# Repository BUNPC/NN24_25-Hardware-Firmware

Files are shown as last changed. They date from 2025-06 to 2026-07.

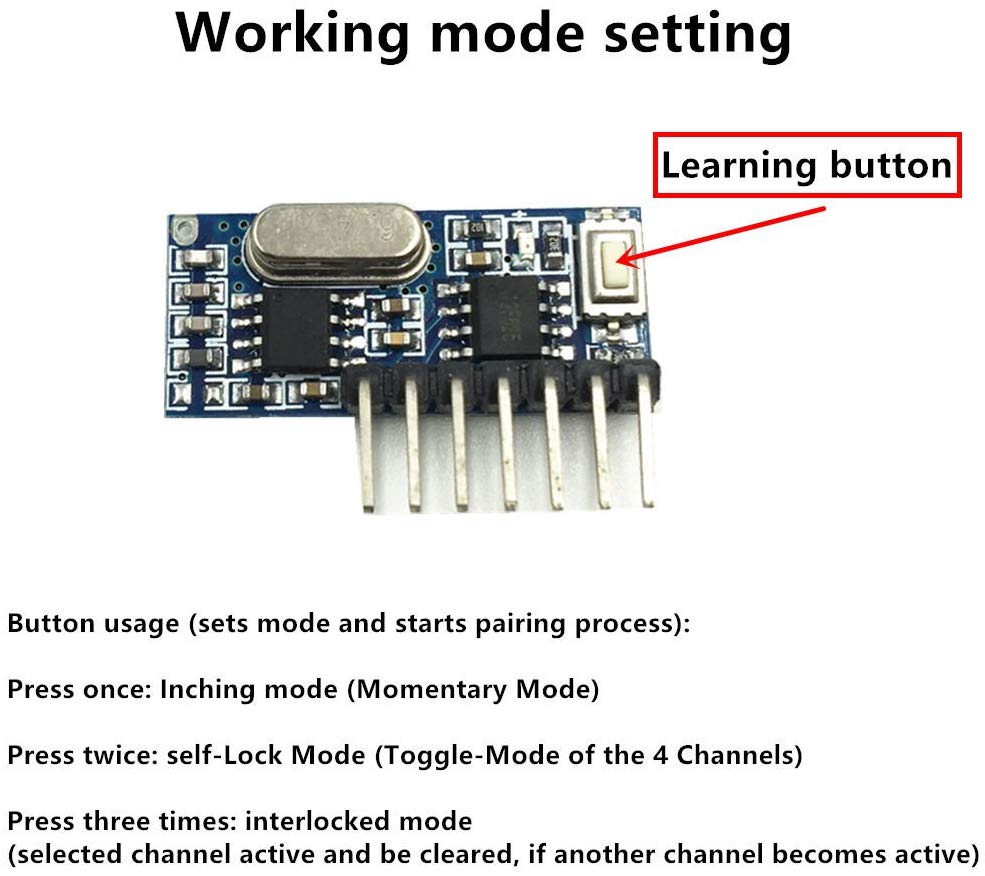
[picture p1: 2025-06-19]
Hardware Peripherial/ninjaNIRS Triggerbox/hardware/Rev1a_Eagle/61eN8m-au2L._AC_SL1001_.jpg

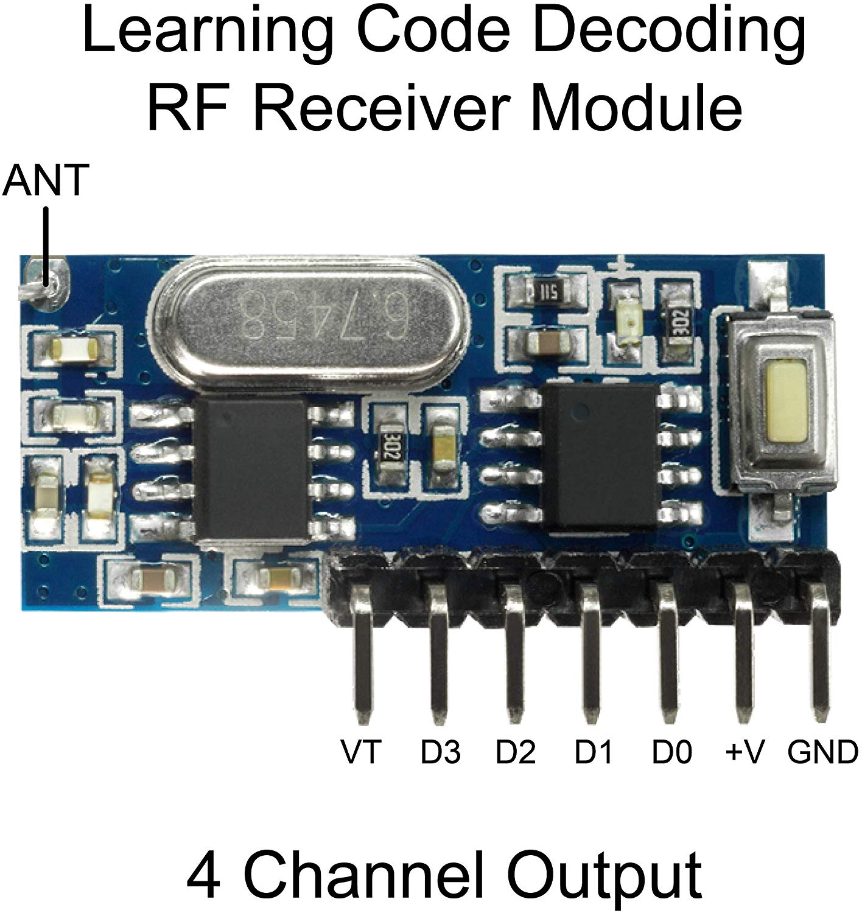
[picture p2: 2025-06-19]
Hardware Peripherial/ninjaNIRS Triggerbox/hardware/Rev1a_Eagle/81+gmd-v-IL._AC_SL1500_.jpg

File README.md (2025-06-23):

This repository contains the technical documentation used to create all parts of the NN24 whole-head fNIRS system.

A description of the documents contained in this respository and other instructions related to the ninjaNIRS system can be found at openfnirs.org [here](https://openfnirs.org/hardware/ninjanirs2024/).

Please refer to the [ninjaNIRS Setup Guide](https://openfnirs.org/wp-content/uploads/2025/06/ninjaNIRS__Setup_Guide.pdf) when assembling your system for the first time to ensure proper configuration and operation.

Please use the [Hardware Forum](https://openfnirs.org/community/hardware-forum/) at openfnirs.org to discuss anything about the ninjaNIRS system.

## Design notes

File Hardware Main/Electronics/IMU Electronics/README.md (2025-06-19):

# IMU Electronics

All IMU electronics files are located in this folder. 

There is not a dedicated IMU backboard part as the IMU interface cards are intended to be used with the existing detector backplanes in place of a detector interface card.

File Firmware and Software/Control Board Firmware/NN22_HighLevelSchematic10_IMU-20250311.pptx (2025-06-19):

## NinjaNIRS 2022 Firmware Schematic and Data Format Specification

Version 2024-7-12
Major change for VCCS source cards
Bernhard Zimmermann – bzim@bu.edu

## Control Card Block Diagram

Boston University Neurophotonics Center

Source Backplane

Detector Backplanes

Detector Backplanes

Detector Backplanes

Detector Backplanes

1 Backplane Connector
21 GPIO
(3 rows + 7x2 columns + 3 power select + 1 spare)

4 Backplane Connectors
Per Connector 17 GPIO
(5 common + 4x3 direct)

UART + SWD + 1 GPIO

2 GPIO (incl I2C)

Aux ADCs

PSRAM

PSRAM

6 GPIO

4 GPIO

2 GPIO

Aux DigIO

Remote Dig In

15 GPIO
UART with CTS/RTS or parallel data

2x6 GPIO

FPGA

4 GPIO

7 GPIO

Spare Con2

Spare Con.

12 GPIO

9 GPIO (incl RPi 0 SPI)

6 GPIO

FTDI USB

UART with RTS/CTS

RP2040

RPi Zero

## FPGA Firmware Block Diagram

27 x 1024
State Sequence RAM A

18 x 1024
Acquisition Sequence RAM B

Status Registers

8 rows
8 columns
3 power select

Source Backplane

Host PC

FTDI USB

USB

UART with RTS/CTS

UART Rx

Config
FSM

Program
Counter A

1 Trigger
1 Trigger Status
1 End Cycle
16 Board Select

+1

Detector Backplanes

Program
Counter B

+1

UART Rx

Clock Divider

readback

Acq
FSM/MUX

FPGA

UART Tx

FIFO

Aux ADC
Interface

## RAM Data Formats

RAM A: State Sequence

| 8 | 7 | 6 | 5 | 4 | 3 | 2 | 1 | 0
state 0 | end | X reserved | | | | | | | stat
⁞
S 1023

End: 1 if last state in sequence: will jump to state 0 next; 0 otherwise: will jump to state i+1 next
X Reserved: reserved for later use
Status: ‘1’ send status packets instead of regular light level packets; ‘0’ send regular packets

RAM B: Acquisition Sequence

| 17 | 16 | 15 | 14 | 13 | 12 | 11 | 10 | 9 | 8 | 7 | 6 | 5 | 4 | 3 | 2 | 1 | 0
State 0 | End | X | X | X | X | X | Src Step | Acq Trg | End cyc | PC Tx Trg | Aux Tx Trg | UART Rx En | UART Rx Mux
⁞
S 1023

End: 1 if last state in sequence: will jump to state 0 next; 0 otherwise: will jump to state i+1 next
X Reserved: reserved for later use
Src Step: Increase the state in the source cards by one
Acq Trg: Transition form ‘0’ to ‘1’ will trigger the acquisition of one sample in the detector boards
End Cyc: Transition form ‘0’ to ‘1’ will cause the detector boards to move the current measurements to the transmit buffer, and reset the sample sums to 0
PC Tx Trg: Program counter A transmit trigger. Transition form ‘0’ to ‘1’ will cause the current program counter A (state) to be transmitted
Aux Tx Trg: Auxillary transmit trigger. Transition form ‘0’ to ‘1’ will cause the current auxiliary ADC values to be transmitted.
UART Rx En: Enable reception of data from the plug-in board selected by UART Rx Mux. Sets CTS for the selected board.
UART Rx Mux: Selects from which plug in board to receive data.

## RAM Data Formats

Source RAM: LED State Sequence
One RAM per source card

| 31 | 30 | 29 | 28 | 27 | 26 | 25 | 24 | 23 | 22 | 21 | 20 | 19 | 18 | 17 | 16 | 15 | …. | 0
State 0 | End | X | X | X | X | X | X | X | X | X | Dummy ENn | LED ENn | LED AD[3..0] | | | | LED Pwr Set (DAC)
⁞
S 1023

End: 1 if last state in sequence: will jump to state 0 next; 0 otherwise: will jump to state i+1 next
X Reserved: reserved for later use
Dummy ENn: Enable dummy load resistor to keep current source in regulation. ‘0’ enabled, ‘1’ disabled.
LED ENn: Enable source LED. ‘0’ enabled, ‘1’ disabled.
LED AD: Select which LED to drive. 0-7 wavelength 1, 8-15 wavelength 2.
LED Pwr Set: Select output current using the digital to analog converter. 0 lowest setting, 65535 highest setting. Highest allowed setting may be lower.

## Status Register Format

Status Register

| 26 | 25 | 24 | 23 | 22 | 21 | 20 | 19 | 18 | 17 | 16 | 15 | 14 | 13 | 12 | 11 | 10 | 9 | 8 | 7 | 6 | 5 | 4 | 3 | 2 | 1 | 0
| Vsrc boost | VN22Clk en | VN3P4 en | VN22 en | V9P0 en | V5P1src en | V5P1RPi off | V5P1B23 en | V5P1B01 en | Clk Div | | | | | | | | Rst Tx FIFO | Rst Ram | Rst PC A | Rst DetB | | | Rst DetB | Rst SrcB | Rst Pico | Run

Vsrc boost: If ‘1’, source board supply voltage will be increased to ~9V.
Clk Div: Clock divider setting. RAM B state period = ClkDiv*8/96MHz
Rst TxFIFO: Reset the FIFO in the data transmitter (FPGA -> PC)
Rst Ram: Reset the PSRAM chip used in the external FIFO.
Rst PC A: Reset program counter A to 0
Rst DetB: Reset the microcontroller on the detector boards by pulling the RUN pins low. Each bit corresponds to one backplane.
Rst SrcB: Reset the microcontroller on the source boards by pulling the RUN pins low.
Rst Pico: Reset the RP2040 (Raspberry Pi Pico) microcontroller on the control board by pulling the RUN pin low.
Run: ‘1’: the clock divider and program counters A and B will run. ‘0’: Divider continues to run until PC B and the divider reach Zero, and then stay there. LED power will be set to 0 immediately.

## Command Format

Command sequence

| byte[0] | byte[1] | byte[2] | byte[3] | byte[4] | byte[5] | byte[6]
| 255 | addr[0] | addr[1] | rdat[0] | rdat[1] | rdat[2] | rdat[3]

Each command starts with a header byte (‘255’), then 2 address bytes, then 4 command payload bytes.
Addr: Address of data to be written or read. (see below)
Rdat: Register or RAM data to be written. Write all ‘0’ when reading a register / RAM location.

Command address format

| 15 | 14 | 13 | 12 | 11 | 10 | 9 | 8 | 7 | 6 | 5 | 4 | 3 | 2 | 1 | 0
| addr[1] | | | | | | | | addr[0]
| r̄/w | addr | X | X | X | X | Acq Trg | End cyc | PC Tx Trg | Aux Tx Trg | DetB Rx En | X | UART Rx Mux

r̄/w: ‘1’: write to the location specified by ‘addr’. ‘0’: read from location ‘addr’. Read is only save if Run = ‘0’.
Addr: Address to be read or written.
0b001 0000 0000 0000 through 0b 001 0011 1111 1111 : RAM A
0b010 0000 0000 0000 through 0b 010 0011 1111 1111 : RAM B
0b100 0000 0000 0001 : Status Register
0b011 xxxx xxxx xxxx : forward packet via UART to plug in boards (board # determined by RAM B)

## Output Data Packet Format

Note: The order of the individual data blocks below is determined by the contents of RAM A. The order shown below is a typical example as also implemented in the MATLAB helper functions.

Output data sequence

| byte[0..2] | byte[(0..7)+3] | byte[(0..27)+11] | … | byte[(0..27)+(n-1)*28+11] | byte[(0..17)+n*28+11]
| PC A packet | Auxiliary pkt | Det adapter pkt | … | Det adapter pkt | Accelerometer pkt

n: number of plugged in Detector Adapter Boards
See following slides for details on the individual packets.

## Program Counter A Packet Format

Packet generated by the FPGA, usually placed at the beginning of a sample/RAM B cycle to help framing the data.
See also PC TX Trg signal in RAM B data format slide.

Output data sequence

| byte[0] | byte[1] | byte[2]
| 254 | PC A [0] | PC A [1]

PC A [1]: high byte of program counter A
PC A [0]: low byte of program counter A

## Auxiliary Packet Format

Data packet generated by the FPGA. Contains the values of the two on-board auxiliary analog to digital converters (ADC). The ADCs are sampled and averaged at the same time and in the same manner as the main ADCs on the detector boards.
The packet also contains the status of the remote trigger signals and the Aux Digital inputs. These signals are sampled a few clock cycles after the rising edge of the “Aux Trg Tx” signal (see RAM B description).

| byte[0] | byte[1] | byte[2] | byte[3] | byte[4] | byte[5] | byte[6] | byte[7]
| 250 | Dig In | ADC0[0] | ADC0[1] | ADC0[2] | ADC1[0] | ADC1[1] | ADC1[2]

Dig In: Remote trigger and aux digital inputs sampled at time of “Aux Trg Tx” signal.
Bits (0..3): remote trigger signals.
Bits (4..5): aux digital inputs.
ADCx: 24 bit sum of all conversions since last “Aux Trg Tx” signal. [2] is the high byte (little endian). Unsigned integer.

Output data sequence

## Detector Adapter Packet Format

Data packet from the RP2040 microcontroller on a detector adapter board. Contains the main light intensity data.

| byte[0] | byte[1] | byte[2] | byte[3] | byte[4] | byte[5] | … | byte[24] | byte[25] | byte[26] | byte[27]
| 253 | 252 | Smp cnt | ADC0[0] | ADC0[1] | ADC0[2] | | ADC7[0] | ADC7[1] | ADC7[2] | 0

Smp cnt: Count of transmitted samples (modulo 256) since last restart of the detector adapter card.
ADCx: 24 bit sum of all conversions since last ‘end cycle’ signal. [2] is the high byte (little endian). Signed integer / two’s complement.

Output data sequence

## Detector Adapter Status Packet Format

Status data packet from the RP2040 microcontroller on a detector adapter board.

| byte[0] | byte[1] | byte[2] | byte[3] | … | byte[10] | byte[11] | byte[12] | byte[13] | byte[14] | byte[15] | byte[16] | byte[17]
| 239 | 238 | Smp cnt | UID[0] | | UID[7] | FWv[0] | FWv[1] | Temp[0] | Temp[1] | 0 | 0 | 0

Smp cnt: Count of transmitted samples (modulo 256) since last restart of the microcontroller.
UID: 64 bit unique ID from flash attached to microcontroller
FW: Firmware version.
Temp: Microcontroller internal temperature.
Conn flag: accelerometer connected flags (acc_connected_before_run<<1) || acc_connected_curr)

Output data sequence

## Accelerometer Packet Format

Data packet from the RP2040 microcontroller on the main control board. Contains the data read out from an IMU attached to the QWIIC port.

| byte[0] | byte[1] | byte[2] | byte[3] | byte[4] | … | byte[15] | byte[16] | byte[17]
| 249 | 248 | Smp cnt | Data0[0] | Data0[1] | | Data6[0] | Data6[1] | 0

Smp cnt: Count of transmitted samples (modulo 256) since last restart of the microcontroller.
Datax: 16 bit data words from the IMU, obtained right after last “End cyc” signal. [1] is the high byte (little endian). Signed integer / two’s complement.
Data0: Temperature
Data1: Gyro X
Data2: Gyro Y
Data3: Gyro Z
Data4: Accelerometer X
Data5: Accelerometer Y
Data6: Accelerometer Z

Output data sequence

## Accelerometer Status Packet Format

Status data packet from the RP2040 microcontroller on the main control board. Contains the controller temperature and board input voltage.

| byte[0] | byte[1] | byte[2] | byte[3] | … | byte[10] | byte[11] | byte[12] | byte[13] | byte[14] | byte[15] | byte[16] | byte[17] | byte[18] | byte[19]
| 237 | 236 | Smp cnt | UID[0] | | UID[7] | FWv[0] | FWv[1] | Temp[0] | Temp[1] | Vin[0] | Vin[1] | Conn flag | 0 | 0

Smp cnt: Count of transmitted samples (modulo 256) since last restart of the microcontroller.
UID: 64 bit unique ID from flash attached to microcontroller
FW: Firmware version.
Temp: Microcontroller internal temperature.
Vin: Control board input voltage.
Conn flag: accelerometer connected flags (acc_connected_before_run<<1) || acc_connected_curr)

Output data sequence

## Summary of Packet Headers

Summary of packet headers from the different data sources.

Packet Type | Header
Command from PC to FPGA | [255]
Reply to command (FPGA => PC) | [240]
Program Counter A Packet | [254]
Auxiliary Data Packet | [250]
Detector Adapter Data Packet | [253 252]
Detector Adapter Status Packet | [239 238]
IMU Controller Data Packet | [249 248]
IMU Controller Status Packet | [237 236]
IMU Adapter Data | [253, 251]
IMU Adapter Status | [239, 237]

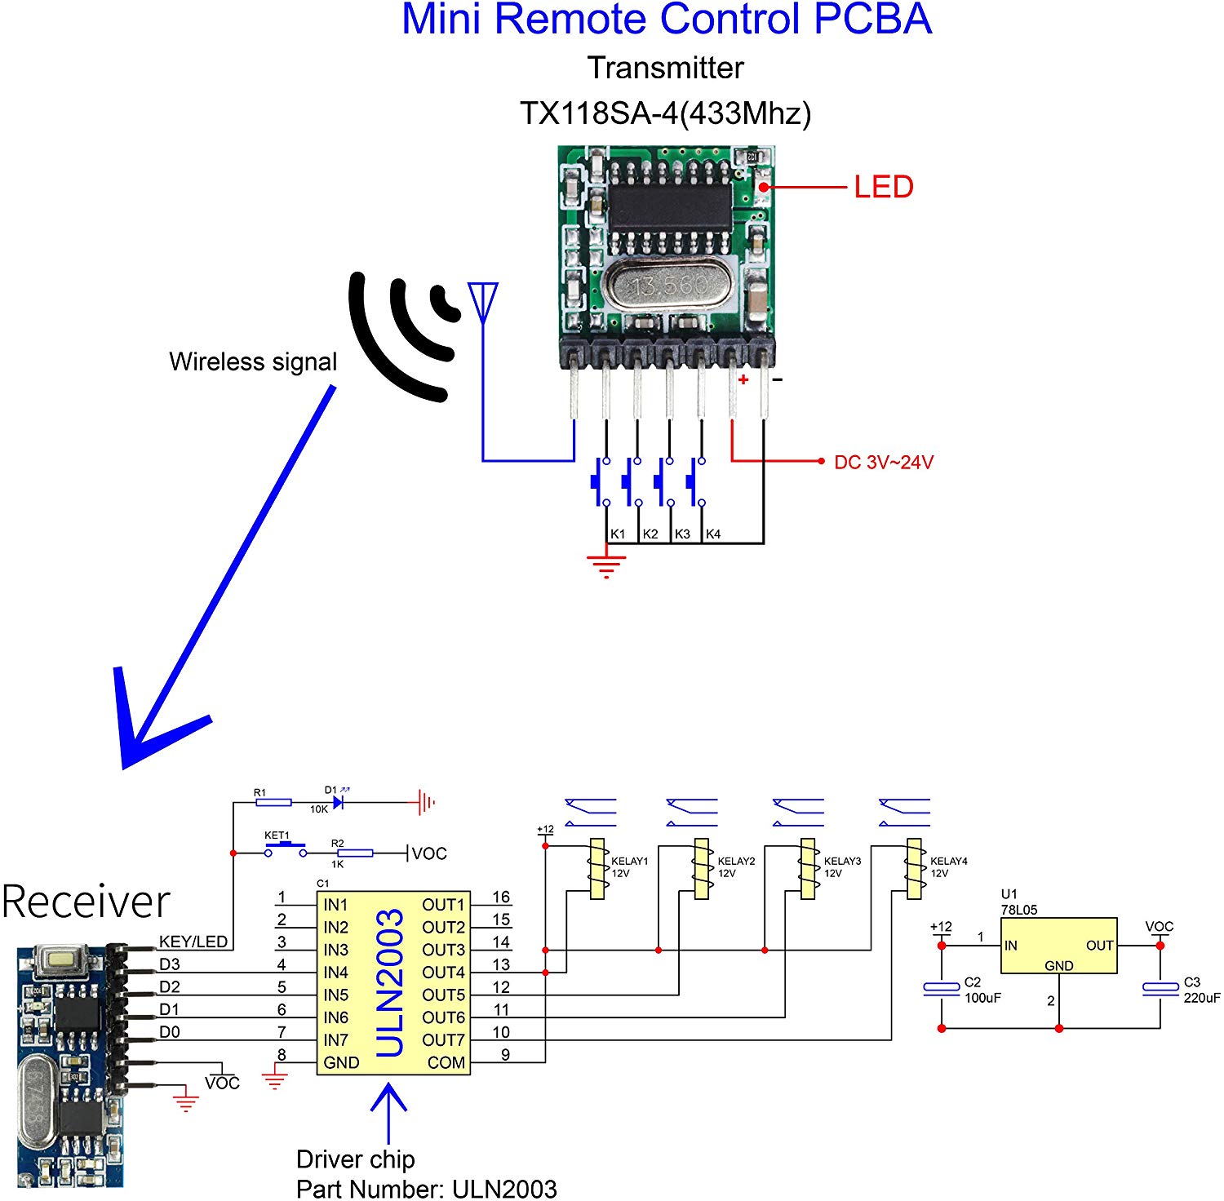
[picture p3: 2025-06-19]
Hardware Peripherial/ninjaNIRS Triggerbox/hardware/Rev1a_Eagle/81bwLxzH8NL._AC_SL1500_.jpg

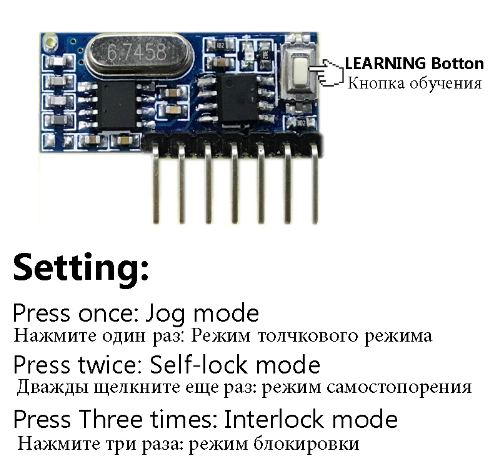
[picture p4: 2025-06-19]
Hardware Peripherial/ninjaNIRS Triggerbox/hardware/Rev1a_Eagle/423790-1a9fda4640fa45f28f44fabd3a5eae38_600x.png

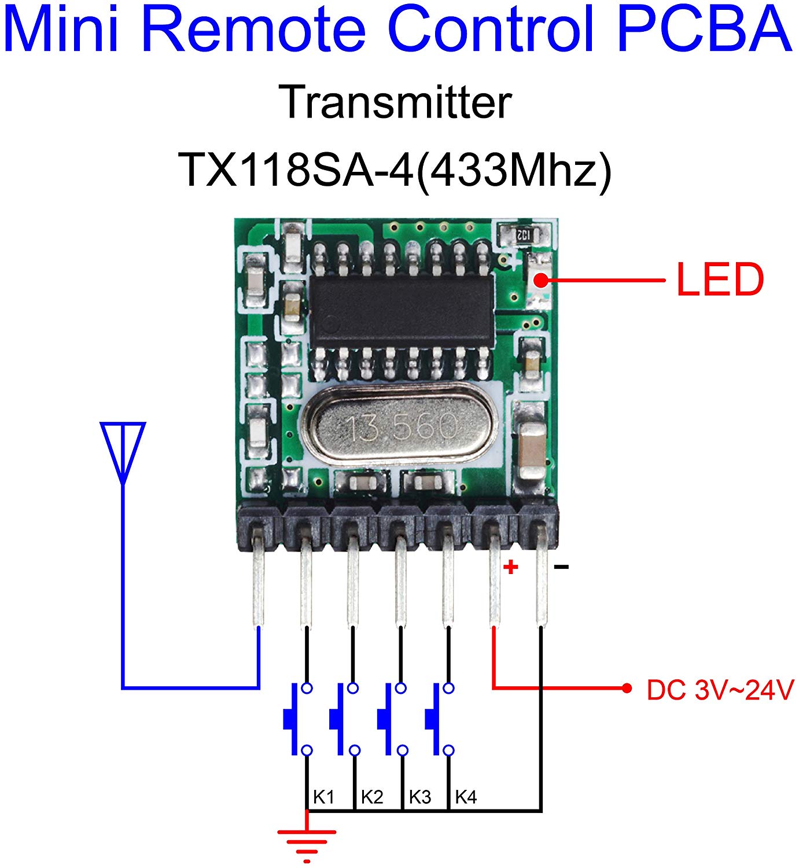
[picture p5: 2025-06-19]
Hardware Peripherial/ninjaNIRS Triggerbox/hardware/Rev1a_Eagle/81kcTXVxWdL._AC_SL1500_.jpg

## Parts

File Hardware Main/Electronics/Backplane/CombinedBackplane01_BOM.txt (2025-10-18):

all plug-in card connectors: Harting 15210402401000 Qty: 30
all control card connectors (Jx04): Harting 15150402601000 Qty: 5 
all other connectors: DNP

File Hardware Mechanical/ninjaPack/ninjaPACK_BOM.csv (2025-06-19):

Line | Qty. | Item | Vendor | Part No.
1 | 4 | M3x0.5mm, 30mm Lg (Enclosure Corners) | McMaster Carr | 92125A140
2 | 4 | M3x0.5mm, 12mm Lg (PCB Corners) | McMaster Carr | 91290A117
3 | 4 | M3 nylon washer (PCB Corners) | McMaster Carr | 95610A330
4 | 8 | M3x0.5mm Hex Nut | McMaster Carr | 90591A250
5 | 4 | M4x0.7mm, 15mm Lg (Battery Carriers) | McMaster Carr | 91290A306
6 | 4 | M4x0.7mm Hex Nut | McMaster Carr | 90591A255
7 | 2 | Dewalt 12V battery adapter | Amazon | B09N42RJKW | https://a.co/d/3aEim6k
8 | 1 | WOJ-DBENC-001-RevAB (Dual Battery Enclosure Lid)
9 | 1 | WOJ-DBENC-002-RevAB (Dual Battery Enclosure Base)
10 | 1 | WOJ-DBPCB-SA-001-RevAB (Dual Battery PCB Subassembly)

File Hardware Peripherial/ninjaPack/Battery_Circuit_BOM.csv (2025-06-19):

Part | Value | Device | Package | Description | ARROW_PART_NUMBER | ARROW_PRICE-STOCK | DESCRIPTION | HEIGHT | MANUFACTURER_NAME | MANUFACTURER_PART_NUMBER | MOUSER_PART_NUMBER | MOUSER_PRICE-STOCK | PROD_ID | VALUE
C1 | 0.1uF | 0.1UF-KIT-EZ-50V-20% | CAP-PTH-SMALL-KIT | 0.1µF ceramic capacitors |  |  |  |  |  |  |  |  | CAP-08370 | 0.1uF
C2 | 0.1uF | 0.1UF-KIT-EZ-50V-20% | CAP-PTH-SMALL-KIT | 0.1µF ceramic capacitors |  |  |  |  |  |  |  |  | CAP-08370 | 0.1uF
IC2 | LTC4357IMS8#TRPBF | LTC4357IMS8#TRPBF | SOP65P490X110-8N | Hot Swap Controller 1-CH 80V N-Channel Positive High Voltage Automotive 8-Pin MSOP T/R | LTC4357IMS8#TRPBF | https://www.arrow.com/en/products/ltc4357ims8trpbf/analog-devices?region=nac | Hot Swap Controller 1-CH 80V N-Channel Positive High Voltage Automotive 8-Pin MSOP T/R | 1.1mm | Analog Devices | LTC4357IMS8#TRPBF | 584-LTC4357IMS8TRPBF | https://www.mouser.co.uk/ProductDetail/Analog-Devices/LTC4357IMS8TRPBF?qs=hVkxg5c3xu9xOCu4lpdF5Q%3D%3D
IC3 | LTC4357IMS8#TRPBF | LTC4357IMS8#TRPBF | SOP65P490X110-8N | Hot Swap Controller 1-CH 80V N-Channel Positive High Voltage Automotive 8-Pin MSOP T/R | LTC4357IMS8#TRPBF | https://www.arrow.com/en/products/ltc4357ims8trpbf/analog-devices?region=nac | Hot Swap Controller 1-CH 80V N-Channel Positive High Voltage Automotive 8-Pin MSOP T/R | 1.1mm | Analog Devices | LTC4357IMS8#TRPBF | 584-LTC4357IMS8TRPBF | https://www.mouser.co.uk/ProductDetail/Analog-Devices/LTC4357IMS8TRPBF?qs=hVkxg5c3xu9xOCu4lpdF5Q%3D%3D
Q1 | RD3P08BBDTL | RD3P08BBDTL | RD3P175SNFRATL | RD3P08BBDTL N-Channel MOSFET, 80 A, 100 V RD3P08BBD, 3-Pin DPAK ROHM |  |  | RD3P08BBDTL N-Channel MOSFET, 80 A, 100 V RD3P08BBD, 3-Pin DPAK ROHM | mm | ROHM Semiconductor | RD3P08BBDTL | 755-RD3P08BBDTL | https://www.mouser.co.uk/ProductDetail/ROHM-Semiconductor/RD3P08BBDTL?qs=qSfuJ%252Bfl%2Fd6NkJEicmek1A%3D%3D
Q2 | RD3P08BBDTL | RD3P08BBDTL | RD3P175SNFRATL | RD3P08BBDTL N-Channel MOSFET, 80 A, 100 V RD3P08BBD, 3-Pin DPAK ROHM |  |  | RD3P08BBDTL N-Channel MOSFET, 80 A, 100 V RD3P08BBD, 3-Pin DPAK ROHM | mm | ROHM Semiconductor | RD3P08BBDTL | 755-RD3P08BBDTL | https://www.mouser.co.uk/ProductDetail/ROHM-Semiconductor/RD3P08BBDTL?qs=qSfuJ%252Bfl%2Fd6NkJEicmek1A%3D%3D
R1 | 100 | 100OHM-HORIZ-1/4W-1% | AXIAL-0.3 | 100Ω resistor |  |  |  |  |  |  |  |  | RES-12181 | 100
R2 | 100 | 100OHM-HORIZ-1/4W-1% | AXIAL-0.3 | 100Ω resistor |  |  |  |  |  |  |  |  | RES-12181 | 100
S1 | A8L-21-12N2 | A8L-21-12N2 | A8L2112N2 | Rocker Switches ROCKER SWITCH |  |  | Rocker Switches ROCKER SWITCH | 22.1mm | Omron Electronics | A8L-21-12N2 | 653-A8L-21-12N2 | https://www.mouser.co.uk/ProductDetail/Omron-Electronics/A8L-21-12N2?qs=wE98CiVmOw76dmZWfHCJ3A%3D%3D

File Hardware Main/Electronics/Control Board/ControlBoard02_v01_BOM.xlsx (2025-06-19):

Designator | Value | Footprint | Populate | MPN | Manufacturer | MPN | Manufacturer
C1001 | 0.1u | 0402-CAP | 1 | GRM155R71H104KE14D | Murata
C1002 | 0.1u | 0402-CAP | 1 | GRM155R71H104KE14D | Murata
C1003 | 4.7u | 0402-CAP | 1 | CL05A475MP5NRNC | Samsung
C1004 | 22u | 0805-CAP | 1 | CL21A226MAYNNNE | Samsung
C1005 | 10n | 0603-CAP | 1 | GRM1885C1H103JA01D | Murata
C1006 | 0.1u | 0402-CAP | 1 | GRM155R71H104KE14D | Murata
C1007 | 4.7u | 0402-CAP | 1 | CL05A475MP5NRNC | Samsung
C1008 | 4.7u | 0402-CAP | 1 | CL05A475MP5NRNC | Samsung
C1009 | 0.1u | 0402-CAP | 1 | GRM155R71H104KE14D | Murata
C101 | 0.1u | 0402-CAP | 1 | GRM155R71H104KE14D | Murata
C1010 | 0.1u | 0402-CAP | 1 | GRM155R71H104KE14D | Murata
C201 | 0.1u | 0402-CAP | 1 | GRM155R71H104KE14D | Murata
C202 | 0.1u | 0402-CAP | 1 | GRM155R71H104KE14D | Murata
C203 | 0.1u | 0402-CAP | 1 | GRM155R71H104KE14D | Murata
C204 | 0.1u | 0402-CAP | 1 | GRM155R71H104KE14D | Murata
C205 | 27p | 0402-CAP | 1 | GCM1555C1H270JA16D | Murata
C206 | 27p | 0402-CAP | 1 | GCM1555C1H270JA16D | Murata
C207 | 0.1u | 0402-CAP | 1 | GRM155R71H104KE14D | Murata
C301 | 0.1u | 0402-CAP | 1 | GRM155R71H104KE14D | Murata
C501 | 0.1u | 0402-CAP | 1 | GRM155R71H104KE14D | Murata
C502 | 4.7u | 0402-CAP | 1 | CL05A475MP5NRNC | Samsung
C503 | 10n | 0603-CAP | 1 | GRM1885C1H103JA01D | Murata
C504 | 0.1u | 0402-CAP | 1 | GRM155R71H104KE14D | Murata
C505 | 10n | 0603-CAP | 1 | GRM1885C1H103JA01D | Murata
C506 | 22u | 0805-CAP | 1 | CL21A226MAYNNNE | Samsung
C507 | 0.1u | 0402-CAP | 1 | GRM155R71H104KE14D | Murata
C508 | 0.1u | 0402-CAP | 1 | GRM155R71H104KE14D | Murata
C509 | 4.7u | 0402-CAP | 1 | CL05A475MP5NRNC | Samsung
C510 | 4.7u | 0402-CAP | 1 | CL05A475MP5NRNC | Samsung
C601 | 4.7u | 0402-CAP | 1 | CL05A475MP5NRNC | Samsung
C602 | 4.7u | 0402-CAP | 1 | CL05A475MP5NRNC | Samsung
C603 | 0.1u | 0402-CAP | 1 | GRM155R71H104KE14D | Murata
C604 | 4.7u | 0402-CAP | 1 | CL05A475MP5NRNC | Samsung
C605 | 4.7u | 0402-CAP | 1 | CL05A475MP5NRNC | Samsung
C606 | 0.1u | 0402-CAP | 1 | GRM155R71H104KE14D | Murata
C607 | 0.1u | 0402-CAP | 1 | GRM155R71H104KE14D | Murata
C608 | 0.1u | 0402-CAP | 1 | GRM155R71H104KE14D | Murata
C609 | 22u | 0805-CAP | 1 | CL21A226MAYNNNE | Samsung
C610 | 4.7u | 0402-CAP | 1 | CL05A475MP5NRNC | Samsung
C611 | 27p | 0402-CAP | 1 | GCM1555C1H270JA16D | Murata
C612 | 27p | 0402-CAP | 1 | GCM1555C1H270JA16D | Murata
C613 | 0.1u | 0402-CAP | 1 | GRM155R71H104KE14D | Murata
C614 | 0.1u | 0402-CAP | 1 | GRM155R71H104KE14D | Murata
C615 | 0.1u | 0402-CAP | 1 | GRM155R71H104KE14D | Murata
C616 | 0.1u | 0402-CAP | 1 | GRM155R71H104KE14D | Murata
C617 | 0.1u | 0402-CAP | 1 | GRM155R71H104KE14D | Murata
C618 | DNP | 1210 | 0
C619 | 0.1u | 0402-CAP | 1 | GRM155R71H104KE14D | Murata
C620 | 0.1u | 0402-CAP | 1 | GRM155R71H104KE14D | Murata
C621 | 0.1u | 0402-CAP | 1 | GRM155R71H104KE14D | Murata
C622 | 0.1u | 0402-CAP | 1 | GRM155R71H104KE14D | Murata
C623 | 0.1u | 0402-CAP | 1 | GRM155R71H104KE14D | Murata
C624 | 0.1u | 0402-CAP | 1 | GRM155R71H104KE14D | Murata
C625 | 0.1u | 0402-CAP | 1 | GRM155R71H104KE14D | Murata
C626 | 0.1u | 0402-CAP | 1 | GRM155R71H104KE14D | Murata
C701 | 22p | 0402-CAP | 1 | GCM1555C1H220JA16D | Murata
C702 | 22u | 0805-CAP | 1 | CL21A226MAYNNNE | Samsung
C703 | 22u | 0805-CAP | 1 | CL21A226MAYNNNE | Samsung
C704 | 22u | 0805-CAP | 1 | CL21A226MAYNNNE | Samsung
C705 | 100u/25V | 2917-CAP | 1 | TCJD107M025R0055 | KYOCERA AVX
C706 | 22u | 0805-CAP | 1 | CL21A226MAYNNNE | Samsung
C707 | 100u/25V | 2917-CAP | 1 | TCJD107M025R0055 | KYOCERA AVX
C708 | 100u/25V | 2917-CAP | 1 | TCJD107M025R0055 | KYOCERA AVX
C709 | 22u | 0805-CAP | 1 | CL21A226MAYNNNE | Samsung
C710 | 22u | 0805-CAP | 1 | CL21A226MAYNNNE | Samsung
C711 | 39p | 0402-CAP | 1 | CC0402JRNPO9BN390 | Yageo
C712 | 22u | 0805-CAP | 1 | CL21A226MAYNNNE | Samsung
C713 | 22u | 0805-CAP | 1 | CL21A226MAYNNNE | Samsung
C714 | 22u | 0805-CAP | 1 | CL21A226MAYNNNE | Samsung
C715 | 39p | 0402-CAP | 1 | CC0402JRNPO9BN390 | Yageo
C716 | 22u | 0805-CAP | 1 | CL21A226MAYNNNE | Samsung
C717 | 22u | 0805-CAP | 1 | CL21A226MAYNNNE | Samsung
C718 | 330u/25V | CAP-SMD-POL-8X10 | 1 | EEE-FP1E331AP | Panasonic
C719 | 22u | 0805-CAP | 1 | CL21A226MAYNNNE | Samsung
C720 | 39p | 0402-CAP | 1 | CC0402JRNPO9BN390 | Yageo
C721 | 22u | 0805-CAP | 1 | CL21A226MAYNNNE | Samsung
C722 | 22u | 0805-CAP | 1 | CL21A226MAYNNNE | Samsung
C723 | 22u | 0805-CAP | 1 | CL21A226MAYNNNE | Samsung
C724 | 39p | 0402-CAP | 1 | CC0402JRNPO9BN390 | Yageo
C725 | 22u | 0805-CAP | 1 | CL21A226MAYNNNE | Samsung
C726 | 22u | 0805-CAP | 1 | CL21A226MAYNNNE | Samsung
C727 | 22u | 0805-CAP | 1 | CL21A226MAYNNNE | Samsung
C728 | 22u | 0805-CAP | 1 | CL21A226MAYNNNE | Samsung
C729 | 10n | 0603-CAP | 1 | GRM1885C1H103JA01D | Murata
C730 | 1n | 0603-CAP | 1 | GRM1885C1H102JA01D | Murata
C731 | 22u | 0805-CAP | 1 | CL21A226MAYNNNE | Samsung
C801 | 100u/25V | 2917-CAP | 1 | TCJD107M025R0055 | KYOCERA AVX
C802 | 4.7u | 0805-CAP | 1 | CL21A475KBQNNNE | Samsung
C803 | 4.7u | 0805-CAP | 1 | CL21A475KBQNNNE | Samsung
C804 | 10u | 1206 | 1 | CL31A106MBHNNNE | Samsung
C805 | 10u | 1206 | 1 | CL31A106MBHNNNE | Samsung
C806 | 10u | 1206 | 1 | CL31A106MBHNNNE | Samsung
C807 | 4.7u | 0805-CAP | 1 | CL21A475KBQNNNE | Samsung
C808 | 4.7u | 0805-CAP | 1 | CL21A475KBQNNNE | Samsung
C809 | 4.7u | 0805-CAP | 1 | CL21A475KBQNNNE | Samsung
C810 | 4.7u | 0805-CAP | 1 | CL21A475KBQNNNE | Samsung
C811 | 1u | 0603-CAP | 1 | CL10A105KB8NNNC | Samsung
C812 | 100u/25V | 2917-CAP | 1 | TCJD107M025R0055 | KYOCERA AVX
C813 | 4.7u | 0805-CAP | 1 | CL21A475KBQNNNE | Samsung
C814 | 4.7u | 0805-CAP | 1 | CL21A475KBQNNNE | Samsung
C815 | 10u | 1206 | 1 | CL31A106MBHNNNE | Samsung
C816 | 10u | 1206 | 1 | CL31A106MBHNNNE | Samsung
C817 | 10u | 1206 | 1 | CL31A106MBHNNNE | Samsung
C818 | 4.7u | 0805-CAP | 1 | CL21A475KBQNNNE | Samsung
C819 | 4.7u | 0805-CAP | 1 | CL21A475KBQNNNE | Samsung
C820 | 4.7u | 0805-CAP | 1 | CL21A475KBQNNNE | Samsung
C821 | 4.7u | 0805-CAP | 1 | CL21A475KBQNNNE | Samsung
C822 | 1u | 0603-CAP | 1 | CL10A105KB8NNNC | Samsung
C823 | 4.7u | 0805-CAP | 1 | CL21A475KBQNNNE | Samsung
C824 | 4.7u | 0805-CAP | 1 | CL21A475KBQNNNE | Samsung
C825 | 100u | 1206 | 1 | CL31A107MQHNNNE | Samsung
C826 | 100u | 1206 | 1 | CL31A107MQHNNNE | Samsung
C827 | DNP | 1206 | 0
C828 | 4.7u | 0805-CAP | 1 | CL21A475KBQNNNE | Samsung
C829 | 4.7u | 0805-CAP | 1 | CL21A475KBQNNNE | Samsung
C830 | 1u | 0603-CAP | 1 | CL10A105KB8NNNC | Samsung
C831 | 100u/25V | 2917-CAP | 1 | TCJD107M025R0055 | KYOCERA AVX
C901 | 22u | 0805-CAP | 1 | CL21A226MAYNNNE | Samsung
C902 | 22u | 0805-CAP | 1 | CL21A226MAYNNNE | Samsung
C903 | 22u | 0805-CAP | 1 | CL21A226MAYNNNE | Samsung
C904 | 4.7u | 0402-CAP | 1 | CL05A475MP5NRNC | Samsung
C905 | 4.7u | 0402-CAP | 1 | CL05A475MP5NRNC | Samsung
C906 | 4.7u | 0402-CAP | 1 | CL05A475MP5NRNC | Samsung
C907 | 4.7u | 0402-CAP | 1 | CL05A475MP5NRNC | Samsung
C908 | 4.7u | 0402-CAP | 1 | CL05A475MP5NRNC | Samsung
C909 | 4.7u | 0402-CAP | 1 | CL05A475MP5NRNC | Samsung
C910 | 4.7u | 0402-CAP | 1 | CL05A475MP5NRNC | Samsung
C911 | 4.7u | 0402-CAP | 1 | CL05A475MP5NRNC | Samsung
C912 | 4.7u | 0402-CAP | 1 | CL05A475MP5NRNC | Samsung
C913 | 4.7u | 0402-CAP | 1 | CL05A475MP5NRNC | Samsung
C914 | 4.7u | 0402-CAP | 1 | CL05A475MP5NRNC | Samsung
C915 | DNP | 0805-CAP | 0
C916 | 0.1u | 0402-CAP | 1 | GRM155R71H104KE14D | Murata
C917 | 0.1u | 0402-CAP | 1 | GRM155R71H104KE14D | Murata
C918 | 0.1u | 0402-CAP | 1 | GRM155R71H104KE14D | Murata
C919 | 0.1u | 0402-CAP | 1 | GRM155R71H104KE14D | Murata
C920 | 0.1u | 0402-CAP | 1 | GRM155R71H104KE14D | Murata
C921 | 0.1u | 0402-CAP | 1 | GRM155R71H104KE14D | Murata
C922 | 0.1u | 0402-CAP | 1 | GRM155R71H104KE14D | Murata
C923 | 0.1u | 0402-CAP | 1 | GRM155R71H104KE14D | Murata
C924 | 0.1u | 0402-CAP | 1 | GRM155R71H104KE14D | Murata
C925 | 0.1u | 0402-CAP | 1 | GRM155R71H104KE14D | Murata
C926 | 0.1u | 0402-CAP | 1 | GRM155R71H104KE14D | Murata
C927 | 0.1u | 0402-CAP | 1 | GRM155R71H104KE14D | Murata
C928 | 0.1u | 0402-CAP | 1 | GRM155R71H104KE14D | Murata
C929 | 0.1u | 0402-CAP | 1 | GRM155R71H104KE14D | Murata
C930 | 0.1u | 0402-CAP | 1 | GRM155R71H104KE14D | Murata
C931 | 0.1u | 0402-CAP | 1 | GRM155R71H104KE14D | Murata
C932 | 0.1u | 0402-CAP | 1 | GRM155R71H104KE14D | Murata
C933 | 0.1u | 0402-CAP | 1 | GRM155R71H104KE14D | Murata
C934 | 0.1u | 0402-CAP | 1 | GRM155R71H104KE14D | Murata
C935 | 0.1u | 0402-CAP | 1 | GRM155R71H104KE14D | Murata
C936 | 0.1u | 0402-CAP | 1 | GRM155R71H104KE14D | Murata
C937 | 0.1u | 0402-CAP | 1 | GRM155R71H104KE14D | Murata
C938 | 0.1u | 0402-CAP | 1 | GRM155R71H104KE14D | Murata
C939 | 0.1u | 0402-CAP | 1 | GRM155R71H104KE14D | Murata
C940 | 0.1u | 0402-CAP | 1 | GRM155R71H104KE14D | Murata
C941 | 0.1u | 0402-CAP | 1 | GRM155R71H104KE14D | Murata
C942 | 0.1u | 0402-CAP | 1 | GRM155R71H104KE14D | Murata
C943 | 22p | 0402-CAP | 1 | GCM1555C1H220JA16D | Murata
C944 | 22u | 0805-CAP | 1 | CL21A226MAYNNNE | Samsung
D101 | D1213A-02SO | SOT23-6 | 1 | D1213A-02SO-7 | Diodes Inc.
D201 | D1213A-02SO | SOT23-6 | 1 | D1213A-02SO-7 | Diodes Inc.
D202 | D1213A-02SO | SOT23-6 | 1 | D1213A-02SO-7 | Diodes Inc.
D203 |  | SOD523 | 1 | SBR1A20T5-7 | Diodes Inc.
D204 | D1213A-02SO | SOT23-6 | 1 | D1213A-02SO-7 | Diodes Inc.
D501 | D1213A-02SO | SOT23-6 | 1 | D1213A-02SO-7 | Diodes Inc.
D502 | D1213A-02SO | SOT23-6 | 1 | D1213A-02SO-7 | Diodes Inc.
D503 | D1213A-02SO | SOT23-6 | 1 | D1213A-02SO-7 | Diodes Inc.
D601 | PACDN042 | SOT23-3 | 1 | PACDN042Y3R | onsemi
D602 | D1213A-02SO | SOT23-6 | 1 | D1213A-02SO-7 | Diodes Inc.
D701 |  | SOD128 | 1 | CMS05(TE12L,Q,M) | Toshiba
D702 |  | SOD128 | 1 | CMS05(TE12L,Q,M) | Toshiba
D703 |  | SOD128 | 1 | CMS05(TE12L,Q,M) | Toshiba
D704 |  | SOD128 | 1 | CMS05(TE12L,Q,M) | Toshiba
F101 | 0ZCM0010FF2G | 0603-RES | 1 | 0ZCM0010FF2G | Bel Fuse
F201 | 0ZCM0010FF2G | 0603-RES | 1 | 0ZCM0010FF2G | Bel Fuse
F202 | 0ZCM0010FF2G | 0603-RES | 1 | 0ZCM0010FF2G | Bel Fuse
F203 | 0ZCM0010FF2G | 0603-RES | 1 | 0ZCM0010FF2G | Bel Fuse
F701 | 2920L600/16MR | 2920-FUSE | 1 | 2920L600/16MR | Littelfuse
FID901 | FIDUCIALUFIDUCIAL | MICRO-FIDUCIAL | 0
FID902 | FIDUCIALUFIDUCIAL | MICRO-FIDUCIAL | 0
FID903 | FIDUCIALUFIDUCIAL | MICRO-FIDUCIAL | 0
FID904 | FIDUCIALUFIDUCIAL | MICRO-FIDUCIAL | 0
FID905 | FIDUCIALUFIDUCIAL | MICRO-FIDUCIAL | 0
FID906 | FIDUCIALUFIDUCIAL | MICRO-FIDUCIAL | 0
FID907 | FIDUCIALUFIDUCIAL | MICRO-FIDUCIAL | 0
J1001 | U.FL | U.FL | 1 | 1909763-1 | TE Connectivity
J101 | M20X2_PTH | M20X2_PTH | 1 | PPPC202LFBN-RC | Sullins
J102 | M04X1_JST_SH_RA | M04X1_JST_SH_SM_RA | 1 | SM04B-SRSS-TB(LF)(SN) | JST
J103 | M04X1_JST_SH_RA | M04X1_JST_SH_SM_RA | 1 | SM04B-SRSS-TB(LF)(SN) | JST
J201 | M04X1_JST_SH_RA | M04X1_JST_SH_SM_RA | 1 | SM04B-SRSS-TB(LF)(SN) | JST
J202 | M04X1_JST_SH_RA | M04X1_JST_SH_SM_RA | 1 | SM04B-SRSS-TB(LF)(SN) | JST
J203 | USB-MICRO | USB-MICRO | 1 | 10118194-0001LF | Amphenol Communications Solutions
J204 | M04X2_0.050_SMD_NO_CREAM | M04X2_0.050_SMD_NO_CREAM | 0
J205 | M04X2_0.050_SMD_NO_CREAM | M04X2_0.050_SMD_NO_CREAM | 0
J206 |  | MOLEX-1X3 | 1 | 22-11-2032 | Molex
J207 |  | MOLEX-1X3 | 0 | 22-11-2032 | Molex
J301 | M04X2_0.050_SMD_NO_CREAM | M04X2_0.050_SMD_NO_CREAM | 0
J302 | M03X2PTH | 2X3-NS | 1 | 67997-206HLF | Amphenol Communications Solutions
J303 | M05X2_SMD_0.050_NOCREAM | M05X2_0.050_SMD_NO_CREAM | 0
J304 | M05X2_SMD_0.050_NOCREAM | M05X2_0.050_SMD_NO_CREAM | 0
J401 | M20X2_HARFLEX_M | M20X2_HARFLEX_M | 1 | 15150402601000 | HARTING Elektronik
J402 | M20X2_HARFLEX_M | M20X2_HARFLEX_M | 1 | 15150402601000 | HARTING Elektronik
J403 | M20X2_HARFLEX_M | M20X2_HARFLEX_M | 1 | 15150402601000 | HARTING Elektronik
J404 | M20X2_HARFLEX_M | M20X2_HARFLEX_M | 1 | 15150402601000 | HARTING Elektronik
J405 | M20X2_HARFLEX_M | M20X2_HARFLEX_M | 1 | 15150402601000 | HARTING Elektronik
J501 | SMAMMCX_PTH | MMCX_PTH_STR | 1 | 73415-1001 | Molex
J502 | SMAMMCX_PTH | MMCX_PTH_STR | 1 | 73415-1001 | Molex
J503 | SMAMMCX_PTH | MMCX_PTH_STR | 1 | 73415-1001 | Molex
J504 | SMAMMCX_PTH | MMCX_PTH_STR | 1 | 73415-1001 | Molex
J505 | SMAMMCX_PTH | MMCX_PTH_STR | 1 | 73415-1001 | Molex
J506 | SMAMMCX_PTH | MMCX_PTH_STR | 1 | 73415-1001 | Molex
J507 | U.FL | U.FL | 1 | 1909763-1 | TE Connectivity
J601 | USB-MICRO | USB-MICRO | 1 | 10118194-0001LF | Amphenol Communications Solutions
J602 | M04X2_0.050_SMD_NO_CREAM | M04X2_0.050_SMD_NO_CREAM | 0
J603 | M13X2_0.050_SHF_NO_CREAM | M13X2_0.050_SHF_NO_CREAM | 0
J604 | M07X1_PTH | M07X1_PTH | 1 | PPPC071LFBN-RC | Sullins
J701 | M04X2_SHROUDED | M04X2-SHROUDED | 1 | 75869-332LF | Amphenol Communications Solutions
J702 | POWERJACK_PJ051AH | PJ051AH | 1 | PJ-051AH | CUI Devices
LED101 | LTST-C191KRKT | LED-0603 | 1 | LTST-C191KRKT | Lite-On
LED102 | LTST-C191KGKT | LED-0603 | 1 | LTST-C191KGKT | Lite-On
LED201 | LTST-C191KRKT | LED-0603 | 1 | LTST-C191KRKT | Lite-On
LED202 | LTST-C191KGKT | LED-0603 | 1 | LTST-C191KGKT | Lite-On
LED203 | LTST-C191KGKT | LED-0603 | 1 | LTST-C191KGKT | Lite-On
LED301 | LTST-C191KRKT | LED-0603 | 1 | LTST-C191KRKT | Lite-On
LED302 | LTST-C191KGKT | LED-0603 | 1 | LTST-C191KGKT | Lite-On
LED303 | LTST-C191KRKT | LED-0603 | 1 | LTST-C191KRKT | Lite-On
LED304 | LTST-C191KGKT | LED-0603 | 1 | LTST-C191KGKT | Lite-On
LED305 | LTST-C191KRKT | LED-0603 | 1 | LTST-C191KRKT | Lite-On
LED306 | LTST-C191KGKT | LED-0603 | 1 | LTST-C191KGKT | Lite-On
LED601 | LTST-C191KGKT | LED-0603 | 1 | LTST-C191KGKT | Lite-On
LED602 | LTST-C191KGKT | LED-0603 | 1 | LTST-C191KGKT | Lite-On
LED603 | LTST-C191KRKT | LED-0603 | 1 | LTST-C191KRKT | Lite-On
LED604 | LTST-C191KGKT | LED-0603 | 1 | LTST-C191KGKT | Lite-On
LED605 | LTST-C191KRKT | LED-0603 | 1 | LTST-C191KRKT | Lite-On
LED606 | LTST-C191KRKT | LED-0603 | 1 | LTST-C191KRKT | Lite-On
LED901 | LTST-C191KRKT | LED-0603 | 1 | LTST-C191KRKT | Lite-On
LF501 | FERRITE1206 | 1206 | 1 | MH3261-601Y | Bourns
LF601 | FERRITE0603 | 0603-FER | 1 | BLM18PG121SN1D | Murata
LF602 | FERRITE0603 | 0603-FER | 1 | BLM18PG121SN1D | Murata
LF603 | FERRITE1206 | 1206 | 1 | MH3261-601Y | Bourns
LF701 | FERRITE1206 | 1206 | 1 | MH3261-601Y | Bourns
LS601 | PKMCS0909E4000-R1 | XDCR_PKMCS0909E4000-R1 | 1 | PKMCS0909E4000-R1 | Murata
Q201 | MOSFET-NCHANNELSMD | SOT23-3 | 1 | DMG3402L-7 | Diodes Inc.
Q701 | MOSFET-NCHANNELSMD | SOT23-3 | 1 | DMG3402L-7 | Diodes Inc.
Q702 | MOSFET-PCHANNEL_SO8 | SO08 | 1 | SI4431CDY-T1-GE3 | Vishay
R1001 | 15 | 0402-RES | 1 | RC0402FR-0715RL | Yageo
R1002 | 100 | 0402-RES | 1 | RC0402FR-07100RL | Yageo
R1003 | 470 | 0402-RES | 1 | RC0402FR-07470RL | Yageo
R101 | 10k | 0402-RES | 1 | RC0402FR-0710KL | Yageo
R102 | 10k | 0402-RES | 1 | RC0402FR-0710KL | Yageo
R103 | 10k | 0402-RES | 1 | RC0402FR-0710KL | Yageo
R104 | 470 | 0402-RES | 1 | RC0402FR-07470RL | Yageo
R105 | 470 | 0402-RES | 1 | RC0402FR-07470RL | Yageo
R201 | 1k | 0402-RES | 1 | RC0402FR-071KL | Yageo
R202 | DNP | 0402-RES | 0
R203 | 10k | 0402-RES | 1 | RC0402FR-0710KL | Yageo
R204 | 10k | 0402-RES | 1 | RC0402FR-0710KL | Yageo
R205 | 100k | 0402-RES | 1 | RC0402FR-07100KL | Yageo
R206 | 47k | 0402-RES | 1 | RC0402FR-0747KL | Yageo
R207 | 10k | 0402-RES | 1 | RC0402FR-0710KL | Yageo
R208 | 10k | 0402-RES | 1 | RC0402FR-0710KL | Yageo
R209 | 27 | 0402-RES | 1 | RC0402FR-0727RL | Yageo
R210 | 10k | 0402-RES | 1 | RC0402FR-0710KL | Yageo
R211 | 27 | 0402-RES | 1 | RC0402FR-0727RL | Yageo
R212 | DNP | 0402-RES | 0
R213 | 1.2k | 0402-RES | 1 | RC0402FR-071K2L | Yageo
R214 | DNP | 0402-RES | 0
R215 | 470 | 0402-RES | 1 | RC0402FR-07470RL | Yageo
R216 | 470 | 0402-RES | 1 | RC0402FR-07470RL | Yageo
R217 | 100k | 0402-RES | 1 | RC0402FR-07100KL | Yageo
R218 | 10k | 0402-RES | 1 | RC0402FR-0710KL | Yageo
R219 | 470 | 0402-RES | 1 | RC0402FR-07470RL | Yageo
R220 | 470 | 0402-RES | 1 | RC0402FR-07470RL | Yageo
R221 | 100k | 0402-RES | 1 | RC0402FR-07100KL | Yageo
R222 | 470 | 0402-RES | 1 | RC0402FR-07470RL | Yageo
R301 | 10k | 0402-RES | 1 | RC0402FR-0710KL | Yageo
R302 | 10k | 0402-RES | 1 | RC0402FR-0710KL | Yageo
R303 | DNP | 0402-RES | 0
R304 | DNP | 0402-RES | 0
R305 | 10k | 0402-RES | 1 | RC0402FR-0710KL | Yageo
R306 | 10k | 0402-RES | 1 | RC0402FR-0710KL | Yageo
R307 | 10k | 0402-RES | 1 | RC0402FR-0710KL | Yageo
R308 | 470 | 0402-RES | 1 | RC0402FR-07470RL | Yageo
R309 | 470 | 0402-RES | 1 | RC0402FR-07470RL | Yageo
R310 | 470 | 0402-RES | 1 | RC0402FR-07470RL | Yageo
R311 | 470 | 0402-RES | 1 | RC0402FR-07470RL | Yageo
R312 | 10k | 0402-RES | 1 | RC0402FR-0710KL | Yageo
R313 | 470 | 0402-RES | 1 | RC0402FR-07470RL | Yageo
R314 | 470 | 0402-RES | 1 | RC0402FR-07470RL | Yageo
R501 | 1k | 0402-RES | 1 | RC0402FR-071KL | Yageo
R502 | 82 | 0402-RES | 1 | RC0402FR-0782RL | Yageo
R503 | DNP | 0805 | 0
R504 | 10k | 0402-RES | 1 | RC0402FR-0710KL | Yageo
R505 | 1k | 0402-RES | 1 | RC0402FR-071KL | Yageo
R506 | 82 | 0402-RES | 1 | RC0402FR-0782RL | Yageo
R507 | DNP | 0805 | 0
R508 | 10k | 0402-RES | 1 | RC0402FR-0710KL | Yageo
R509 | 100 | 0402-RES | 1 | RC0402FR-07100RL | Yageo
R510 | DNP | 0805 | 0
R511 | 10k | 0402-RES | 1 | RC0402FR-0710KL | Yageo
R512 | 100 | 0402-RES | 1 | RC0402FR-07100RL | Yageo
R513 | DNP | 0805 | 0
R514 | 10k | 0402-RES | 1 | RC0402FR-0710KL | Yageo
R515 | 100 | 0402-RES | 1 | RC0402FR-07100RL | Yageo
R516 | DNP | 0805 | 0
R517 | 10k | 0402-RES | 1 | RC0402FR-0710KL | Yageo
R518 | DNP | 0805 | 0
R519 | 10k | 0402-RES | 1 | RC0402FR-0710KL | Yageo
R520 | 100 | 0402-RES | 1 | RC0402FR-07100RL | Yageo
R521 | 100 | 0402-RES | 1 | RC0402FR-07100RL | Yageo
R601 | 470 | 0402-RES | 1 | RC0402FR-07470RL | Yageo
R602 | 1k | 0402-RES | 1 | RC0402FR-071KL | Yageo
R603 | 10k | 0402-RES | 1 | RC0402FR-0710KL | Yageo
R604 | 10k | 0402-RES | 1 | RC0402FR-0710KL | Yageo
R605 | 10k | 0402-RES | 1 | RC0402FR-0710KL | Yageo
R606 | 1k | 0402-RES | 1 | RC0402FR-071KL | Yageo
R607 | 1k | 0402-RES | 1 | RC0402FR-071KL | Yageo
R608 | 1k | 0402-RES | 1 | RC0402FR-071KL | Yageo
R609 | 3.48k | 0402-RES | 1 | RC0402FR-073K48L | Yageo
R610 | 1k | 0402-RES | 1 | RC0402FR-071KL | Yageo
R611 | 12k | 0402-RES | 1 | RC0402FR-0712KL | Yageo
R612 | 1k | 0402-RES | 1 | RC0402FR-071KL | Yageo
R613 | 1k | 0402-RES | 1 | RC0402FR-071KL | Yageo
R614 | 1k | 0402-RES | 1 | RC0402FR-071KL | Yageo
R615 | 1k | 0402-RES | 1 | RC0402FR-071KL | Yageo
R616 | 1k | 0402-RES | 1 | RC0402FR-071KL | Yageo
R617 | 1k | 0402-RES | 1 | RC0402FR-071KL | Yageo
R618 | 1M | R2010 | 1 | RC2010FK-071ML | Yageo
R619 | 1k | 0402-RES | 1 | RC0402FR-071KL | Yageo
R702 | 47k | 0402-RES | 1 | RC0402FR-0747KL | Yageo
R703 | 100k | 0402-RES | 1 | RC0402FR-07100KL | Yageo
R704 | 6.2k | 0402-RES | 1 | RC0402FR-076K2L | Yageo
R705 | 1k | 0402-RES | 1 | RC0402FR-071KL | Yageo
R706 | 47k | 0402-RES | 1 | RC0402FR-0747KL | Yageo
R707 | 100k | 0402-RES | 1 | RC0402FR-07100KL | Yageo
R708 | 8.66k | 0402-RES | 1 | RC0402FR-078K66L | Yageo
R709 | 1k | 0402-RES | 1 | RC0402FR-071KL | Yageo
R710 | 47k | 0402-RES | 1 | RC0402FR-0747KL | Yageo
R711 | 100k | 0402-RES | 1 | RC0402FR-07100KL | Yageo
R712 | 8.66k | 0402-RES | 1 | RC0402FR-078K66L | Yageo
R713 | 1k | 0402-RES | 1 | RC0402FR-071KL | Yageo
R714 | 47k | 0402-RES | 1 | RC0402FR-0747KL | Yageo
R715 | 100k | 0402-RES | 1 | RC0402FR-07100KL | Yageo
R716 | 8.66k | 0402-RES | 1 | RC0402FR-078K66L | Yageo
R717 | 1k | 0402-RES | 1 | RC0402FR-071KL | Yageo
R718 | 47k | 0402-RES | 1 | RC0402FR-0747KL | Yageo
R719 | 15k | 0402-RES | 1 | RC0402FR-0715KL | Yageo
R720 | 6.2k | 0402-RES | 1 | RC0402FR-076K2L | Yageo
R721 | 100k | 0402-RES | 1 | RC0402FR-07100KL | Yageo
R722 | 0.01 | 1206 | 1 | LVT12R0100FER | Ohmite
R723 | 0.01 | 1206 | 1 | LVT12R0100FER | Ohmite
R724 | 10M | 0805 | 1 | RC0805FR-0710ML | Yageo
R801 | 82 | 0402-RES | 1 | RC0402FR-0782RL | Yageo
R802 | 180k | 0402-RES | 1 | RC0402FR-07180KL | Yageo
R803 | 220k | 0402-RES | 1 | RC0402FR-07220KL | Yageo
R804 | 100k | 0402-RES | 1 | RC0402FR-07100KL | Yageo
R805 | 82 | 0402-RES | 1 | RC0402FR-0782RL | Yageo
R806 | 180k | 0402-RES | 1 | RC0402FR-07180KL | Yageo
R807 | 15 | 0402-RES | 1 | RC0402FR-0715RL | Yageo
R808 | 68k | 0402-RES | 1 | RC0402FR-0768KL | Yageo
R901 | 47k | 0402-RES | 1 | RC0402FR-0747KL | Yageo
R902 | 100k | 0402-RES | 1 | RC0402FR-07100KL | Yageo
R904 | 3.48k | 0402-RES | 1 | RC0402FR-073K48L | Yageo
R905 | 100 | 0402-RES | 1 | RC0402FR-07100RL | Yageo
R906 | 1k | 0402-RES | 1 | RC0402FR-071KL | Yageo
S101 | SWITCH-MOMENTARY-2SMD-3 | TACTILE_SWITCH_SMD-3 | 1 | KMR231NGLFS | C&K Components
S201 | SWITCH-MOMENTARY-2SMD-3 | TACTILE_SWITCH_SMD-3 | 1 | KMR231NGLFS | C&K Components
S202 | SWITCH-MOMENTARY-2SMD-3 | TACTILE_SWITCH_SMD-3 | 1 | KMR231NGLFS | C&K Components
TP1001 | TESTPOINT_ROUND | TESTPAD_ROUND | 0
TP1002 | TESTPOINT_ROUND | TESTPAD_ROUND | 0
TP201 | TESTPOINT_ROUND | TESTPAD_ROUND | 0
TP202 | TESTPOINT_ROUND | TESTPAD_ROUND | 0
TP301 | TESTPOINT_ROUND | TESTPAD_ROUND | 0
TP302 | TESTPOINTPADSMALL | TESTPAD_SMALL | 0
TP501 | TESTPOINT_ROUND | TESTPAD_ROUND | 0
TP502 | TESTPOINT_ROUND | TESTPAD_ROUND | 0
TP601 | TESTPOINT_ROUND | TESTPAD_ROUND | 0
TP602 | TESTPOINT1X01 | 1X01 | 0
TP701 | TESTPOINT_ROUND | TESTPAD_ROUND | 0
TP702 | TESTPOINT_ROUND | TESTPAD_ROUND | 0
TP703 | TESTPOINT_ROUND | TESTPAD_ROUND | 0
TP704 | TESTPOINT_ROUND | TESTPAD_ROUND | 0
TP705 | TESTPOINT_ROUND | TESTPAD_ROUND | 0
TP706 | TESTPOINT_ROUND | TESTPAD_ROUND | 0
TP801 | TESTPOINT_ROUND | TESTPAD_ROUND | 0
TP802 | TESTPOINT_ROUND | TESTPAD_ROUND | 0
TP803 | TESTPOINT_ROUND | TESTPAD_ROUND | 0
TP804 | TESTPOINT_ROUND | TESTPAD_ROUND | 0
TP805 | TESTPOINT_ROUND | TESTPAD_ROUND | 0
TP806 | TESTPOINT_ROUND | TESTPAD_ROUND | 0
TP807 | TESTPOINT_ROUND | TESTPAD_ROUND | 0
TP808 | TESTPOINT_ROUND | TESTPAD_ROUND | 0
TP809 | TESTPOINT_ROUND | TESTPAD_ROUND | 0
TP810 | TESTPOINT_ROUND | TESTPAD_ROUND | 0
TP901 | TESTPOINT_ROUND | TESTPAD_ROUND | 0
TP902 | TESTPOINT_ROUND | TESTPAD_ROUND | 0
TP903 | TESTPOINTTUR | TURRET | 1 | 1573-2 | Keystone
U1001 | REF30XX | SOT23-3 | 1 | NCP51460SN33T1G | onsemi
U1002 | INA21X_DCK | SOT363 | 1 | INA214AIDCKR | Texas Instruments
U1003 | ADS7886 | SOT363 | 1 | ADS7886SDCKT | Texas Instruments
U1004 | ADP7182_WSON | WSON6 | 1 | ADP7182ACPZN-R7 | Analog Devices
U1005 | INA21X_DCK | SOT363 | 1 | INA214AIDCKR | Texas Instruments
U201 | RP2040 | QFN-56_EP | 1 | SC0914(13) | Raspberry Pi
U202 | W25Q_USON | USON8L-2X3MM | 1 | W25Q16JVUXIQ TR | Winbond
U301 | MACHXO2_FTBGA256 | LBGA-256 | 1 | LCMXO2-7000HC-6FTG256C | Lattice Semiconductor
U501 | ADS7886 | SOT363 | 1 | ADS7886SDCKT | Texas Instruments
U502 | LT1801 | SOP65P490X110-8N | 1 | LTC2051HVIMS8#PBF | Analog Devices | TSV912IYST | STMicroelectronics
U503 | ADS7886 | SOT363 | 1 | ADS7886SDCKT | Texas Instruments
U504 | REF30XX | SOT23-3 | 1 | NCP51460SN33T1G | onsemi
U505 | ADP7182_WSON | WSON6 | 1 | ADP7182ACPZN-R7 | Analog Devices
U601 | MCP1755_DFN | DFN8_2X3MM | 1 | MCP1755T-3302E/MC | Microchip
U602 | 93LC56 | SOT23-6 | 1 | 93LC56BT-I/OT | Microchip
U603 | APS6404L | USON8L-2X3MM | 1 | APS6404L-3SQR-ZR | AP Memory
U604 | FT2232H_QFP | QFP50P1200X1200X160-64N | 1 | FT2232HL-REEL | FTDI
U605 | ISO7742_DBQ | SSOP16 | 1 | ISO7742DBQ | Texas Instruments
U606 | ISO7742_DBQ | SSOP16 | 1 | ISO7742DBQ | Texas Instruments
U701 | MPM3630_FULL_CREAM | QFN-20-MPS_FULL_CREAM | 1 | MPM3630GQV-Z | Monolithic Power Systems
U702 | RPL-30 | RPL-30 | 1 | RPL-3.0-R | Recom Power
U703 | RPL-30 | RPL-30 | 1 | RPL-3.0-R | Recom Power
U704 | RPL-30 | RPL-30 | 1 | RPL-3.0-R | Recom Power
U705 | RPL-30 | RPL-30 | 1 | RPL-3.0-R | Recom Power
U801 | LTM4651 | BGA-77 | 1 | LTM4651EY#PBF | Analog Devices
U802 | LTM4651 | BGA-77 | 1 | LTM4651EY#PBF | Analog Devices
U803 | LTM4651 | BGA-77 | 1 | LTM4651EY#PBF | Analog Devices
U901 | MPM3630_FULL_CREAM | QFN-20-MPS_FULL_CREAM | 1 | MPM3630GQV-Z | Monolithic Power Systems
X201 | 403I35D12M00000 | CRYSTAL-3.2-2.5 | 1 | 403I35D12M00000 | CTS Components
X601 | 403I35D12M00000 | CRYSTAL-3.2-2.5 | 1 | 403I35D12M00000 | CTS Components
XO301 | OSCILLATOR_TXO2520 | TXO2520 | 1 | ECS-2520MV-480-CN-TR | ECS International

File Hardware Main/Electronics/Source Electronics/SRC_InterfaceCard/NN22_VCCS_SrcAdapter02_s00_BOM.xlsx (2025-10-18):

Designator | Value | Footprint | Populate | MPN | Manufacturer | MPN | Manufacturer
C1 | 0.1u | 0402-CAP | 1 | GRM155R71H104KE14D | Murata
C10 | 0.1u | 0402-CAP | 1 | GRM155R71H104KE14D | Murata
C11 | 10n | 0402-CAP | 1 | CL05B103KB5NNNC | Samsung
C12 | DNP | 0603-CAP | 0
C13 | 100p | 0402-CAP | 1 | CL05C101JB5NNNC | Samsung
C14 | 100p | 0402-CAP | 1 | CL05C101JB5NNNC | Samsung
C15 | 100p | 0402-CAP | 1 | CL05C101JB5NNNC | Samsung
C16 | 100p | 0402-CAP | 1 | CL05C101JB5NNNC | Samsung
C17 | 0.1u | 0402-CAP | 1 | GRM155R71H104KE14D | Murata
C18 | 27p | 0402-CAP | 1 | GCM1555C1H270JA16D | Murata
C19 | 27p | 0402-CAP | 1 | GCM1555C1H270JA16D | Murata
C2 | 0.1u | 0402-CAP | 1 | GRM155R71H104KE14D | Murata
C20 | 150u | 2917-CAP | 1 | TCJY157M016R0050E | KYOCERA AVX
C21 | 0.1u | 0402-CAP | 1 | GRM155R71H104KE14D | Murata
C22 | 10u | 0603-CAP | 1 | GRM188R6YA106MA73D | Murata
C23 | 0.1u | 0402-CAP | 1 | GRM155R71H104KE14D | Murata
C24 | 10u | 0603-CAP | 1 | GRM188R6YA106MA73D | Murata
C25 | 0.1u | 0402-CAP | 1 | GRM155R71H104KE14D | Murata
C26 | 4.7u | 0402-CAP | 1 | CL05A475MP5NRNC | Samsung
C27 | 4.7u | 0402-CAP | 1 | CL05A475MP5NRNC | Samsung
C28 | 4.7u | 0402-CAP | 1 | CL05A475MP5NRNC | Samsung
C29 | 4.7u | 0402-CAP | 1 | CL05A475MP5NRNC | Samsung
C3 | 0.1u | 0402-CAP | 1 | GRM155R71H104KE14D | Murata
C30 | 0.1u | 0402-CAP | 1 | GRM155R71H104KE14D | Murata
C31 | 4.7u | 0402-CAP | 1 | CL05A475MP5NRNC | Samsung
C32 | DNP | 0402-CAP | 0
C33 | 0.1u | 0402-CAP | 1 | GRM155R71H104KE14D | Murata
C34 | 0.1u | 0402-CAP | 1 | GRM155R71H104KE14D | Murata
C35 | 4.7u | 0402-CAP | 1 | CL05A475MP5NRNC | Samsung
C36 | 0.1u | 0402-CAP | 1 | GRM155R71H104KE14D | Murata
C37 | 4.7u | 0402-CAP | 1 | CL05A475MP5NRNC | Samsung
C38 | 0.1u | 0402-CAP | 1 | GRM155R71H104KE14D | Murata
C39 | 0.1u | 0402-CAP | 1 | GRM155R71H104KE14D | Murata
C4 | 10n | 0402-CAP | 1 | CL05B103KB5NNNC | Samsung
C40 | 4.7u | 0402-CAP | 1 | CL05A475MP5NRNC | Samsung
C41 | 0.1u | 0402-CAP | 1 | GRM155R71H104KE14D | Murata
C42 | 0.1u | 0402-CAP | 1 | GRM155R71H104KE14D | Murata
C43 | 0.1u | 0402-CAP | 1 | GRM155R71H104KE14D | Murata
C44 | 10u | 0603-CAP | 1 | GRM188R6YA106MA73D | Murata
C45 | 10u | 0603-CAP | 1 | GRM188R6YA106MA73D | Murata
C46 | 10u | 0603-CAP | 1 | GRM188R6YA106MA73D | Murata
C5 | 0.1u | 0402-CAP | 1 | GRM155R71H104KE14D | Murata
C6 | 100p | 0402-CAP | 1 | CL05C101JB5NNNC | Samsung
C7 | 0.1u | 0402-CAP | 1 | GRM155R71H104KE14D | Murata
C8 | 0.1u | 0402-CAP | 1 | GRM155R71H104KE14D | Murata
C9 | 100p | 0402-CAP | 1 | CL05C101JB5NNNC | Samsung
D1 | BAV70W | SOT323 | 1 | BAV70WT1G | onsemi
D10 | BAV70W | SOT323 | 1 | BAV70WT1G | onsemi
D11 | BAV70W | SOT323 | 1 | BAV70WT1G | onsemi
D2 | BAV70W | SOT323 | 1 | BAV70WT1G | onsemi
D3 | BAV70W | SOT323 | 1 | BAV70WT1G | onsemi
D4 | BAV70W | SOT323 | 1 | BAV70WT1G | onsemi
D5 | BAV70W | SOT323 | 1 | BAV70WT1G | onsemi
D6 | BAV70W | SOT323 | 1 | BAV70WT1G | onsemi
D7 | BAV70W | SOT323 | 1 | BAV70WT1G | onsemi
D8 | BAV70W | SOT323 | 1 | BAV70WT1G | onsemi
D9 | BAV70W | SOT323 | 1 | BAV70WT1G | onsemi
F1 | 0ZCH0035FF2G | 1210-FUSE | 1 | 0ZCH0035FF2G | Bel Fuse
FID1 | FIDUCIALUFIDUCIAL | MICRO-FIDUCIAL | 0
FID2 | FIDUCIALUFIDUCIAL | MICRO-FIDUCIAL | 0
FID3 | FIDUCIALUFIDUCIAL | MICRO-FIDUCIAL | 0
FID4 | FIDUCIALUFIDUCIAL | MICRO-FIDUCIAL | 0
FID5 | FIDUCIALUFIDUCIAL | MICRO-FIDUCIAL | 0
FID6 | FIDUCIALUFIDUCIAL | MICRO-FIDUCIAL | 0
FID7 | FIDUCIALUFIDUCIAL | MICRO-FIDUCIAL | 0
FID8 | FIDUCIALUFIDUCIAL | MICRO-FIDUCIAL | 0
J1 | M04X2_0.050_SMD_NO_CREAM | M04X2_0.050_SMD_NO_CREAM | 0
J2 | M13X2_0.050_SHF | M13X2_0.050_SHF | 1 | 3220-26-0300-00 | CNC Tech | 3220-26-0300-00-TR | CNC Tech
J3 | M04X2_0.050_SMD_NO_CREAM | M04X2_0.050_SMD_NO_CREAM | 0
J4 | U.FL | U.FL | 1 | 1909763-1 | TE Connectivity
J5 | M20X2_HARFLEX_M | M20X2_HARFLEX_M | 1 | 15150402601000 | HARTING Elektronik
J6 | M03X1_JST_SH_RA | M03X1_JST_SH_SM_RA | 1 | SM03B-SRSS-TB | JST
J7 | USB-MICRO | USB-MICRO | 1 | 10118194-0001LF | Amphenol Communications Solutions
LED1 |  | LED-0603 | 1 | LTST-C191KRKT | Lite-On
LED2 |  | LED-0603 | 1 | LTST-C191KGKT | Lite-On
Q1 | MOSFET-DUAL-N-UDFN8 | UDFN8 | 1 | SSM6N67NU,LF | Toshiba
Q10 | MOSFET-DUAL-N-UDFN8 | UDFN8 | 1 | SSM6N67NU,LF | Toshiba
Q2 | MOSFET-DUAL-N-UDFN8 | UDFN8 | 1 | SSM6N67NU,LF | Toshiba
Q3 | MOSFET-DUAL-N-UDFN8 | UDFN8 | 1 | SSM6N67NU,LF | Toshiba
Q4 | MOSFET-DUAL-N-UDFN8 | UDFN8 | 1 | SSM6N67NU,LF | Toshiba
Q5 | MOSFET-DUAL-N-UDFN8 | UDFN8 | 1 | SSM6N67NU,LF | Toshiba
Q6 | MOSFET-DUAL-N-UDFN8 | UDFN8 | 1 | SSM6N67NU,LF | Toshiba
Q7 | MOSFET-DUAL-N-UDFN8 | UDFN8 | 1 | SSM6N67NU,LF | Toshiba
Q8 | MOSFET-DUAL-N-UDFN8 | UDFN8 | 1 | SSM6N67NU,LF | Toshiba
Q9 | MOSFET-DUAL-N-UDFN8 | UDFN8 | 1 | SSM6N67NU,LF | Toshiba
R1 | 0 | 1206 | 1 | RC1206JR-070RL | Yageo
R10 | 100 | 0402-RES | 1 | RC0402FR-07100RL | Yageo
R11 | 1 | 0603-RES | 1 | RC0603FR-071RL | Yageo
R12 | 150 | 0603-RES | 1 | RC0603FR-07150RL | Yageo
R13 | DNP | 0603-RES | 0
R14 | 1.2k | 0402-RES | 1 | RC0402FR-071K2L | Yageo
R15 | 1.2k | 0402-RES | 1 | RC0402FR-071K2L | Yageo
R16 | 10k | 0402-RES | 1 | RC0402FR-1310KL | Yageo
R17 | 28k | 0402-RES | 1 | RC0402FR-0728KL | Yageo
R18 | 28k | 0402-RES | 1 | RC0402FR-0728KL | Yageo
R19 | 10k | 0402-RES | 1 | RC0402FR-1310KL | Yageo
R2 | 10k | 0402-RES | 1 | RC0402FR-1310KL | Yageo
R20 | 1.2k | 0402-RES | 1 | RC0402FR-071K2L | Yageo
R21 | 100k | 0402-RES | 1 | RC0402FR-07100KL | Yageo
R22 | 100k | 0402-RES | 1 | RC0402FR-07100KL | Yageo
R23 | 1.2k | 0402-RES | 1 | RC0402FR-071K2L | Yageo
R24 | 27 | 0402-RES | 1 | RC0402FR-0727RL | Yageo
R25 | 27 | 0402-RES | 1 | RC0402FR-0727RL | Yageo
R26 | 100k | 0402-RES | 1 | RC0402FR-07100KL | Yageo
R27 | 10k | 0402-RES | 1 | RC0402FR-1310KL | Yageo
R28 | 10k | 0402-RES | 1 | RC0402FR-1310KL | Yageo
R29 | 24k | 0402-RES | 1 | RC0402FR-0724KL | Yageo
R3 | 24k | 0402-RES | 1 | RC0402FR-0724KL | Yageo
R30 | 28k | 0402-RES | 1 | RC0402FR-0728KL | Yageo
R31 | 27 | 0402-RES | 1 | RC0402FR-0727RL | Yageo
R32 | 10k | 0402-RES | 1 | RC0402FR-1310KL | Yageo
R33 | 27 | 0402-RES | 1 | RC0402FR-0727RL | Yageo
R34 | 27 | 0402-RES | 1 | RC0402FR-0727RL | Yageo
R4 | 10k | 0402-RES | 1 | RC0402FR-1310KL | Yageo
R5 | 10k | 0402-RES | 1 | RC0402FR-1310KL | Yageo
R6 | 100 | 0402-RES | 1 | RC0402FR-07100RL | Yageo
R7 | 1.2k | 0402-RES | 1 | RC0402FR-071K2L | Yageo
R8 | 8.2 | R2512 | 1 | ERJ1TRQJ8R2U | Panasonic
R9 | 10 | 0603-RES | 1 | RC0603FR-0710RL | Yageo
S1 | SWITCH-MOMENTARY-2SMD-3 | TACTILE_SWITCH_SMD-3 | 1 | KMR231NGLFS | C&K Components
TP1 | TESTPOINT_ROUND | TESTPAD_ROUND | 0
TP10 | TESTPOINT_ROUND | TESTPAD_ROUND | 0
TP11 | TESTPOINT_ROUND | TESTPAD_ROUND | 0
TP12 | TESTPOINTPADSMALL | TESTPAD_SMALL | 0
TP13 | TESTPOINT1X01 | 1X01 | 0
TP14 | TESTPOINTPADSMALL | TESTPAD_SMALL | 0
TP15 | TESTPOINT_ROUND | TESTPAD_ROUND | 0
TP2 | TESTPOINT_ROUND | TESTPAD_ROUND | 0
TP3 | TESTPOINT_ROUND | TESTPAD_ROUND | 0
TP4 | TESTPOINT_ROUND | TESTPAD_ROUND | 0
TP5 | TESTPOINTPADSMALL | TESTPAD_SMALL | 0
TP6 | TESTPOINTPADSMALL | TESTPAD_SMALL | 0
TP7 | TESTPOINT_ROUND | TESTPAD_ROUND | 0
TP8 | TESTPOINT_ROUND | TESTPAD_ROUND | 0
TP9 | TESTPOINT_ROUND | TESTPAD_ROUND | 0
U1 | 74HC238_TSSOP | TSSOP16 | 1 | SN74HCS238PWR | Texas Instruments
U10 | LDL212_DFN6_3X3 | DFN6_3X3MM | 1 | LDL212PUR | STMicroelectronics
U2 | 74HC238_TSSOP | TSSOP16 | 1 | SN74HCS238PWR | Texas Instruments
U3 | AD5683R_MSOP | MSOP10 | 1 | AD5683RARMZ | Analog Devices
U4 | OPA392_SOT23 | SOT23-5 | 1 | OPA392DBVR | Texas Instruments
U5 | RP2040 | QFN-56_EP | 1 | SC0914(7) | Raspberry Pi
U6 | W25Q_USON | USON8L-2X3MM | 1 | W25Q16JVUXIQ TR | Winbond
U7 | ADP7182_WSON | WSON6 | 1 | ADP7182ACPZN-R7 | Analog Devices
U8 | MCP1755_DFN | DFN8_2X3MM | 1 | MCP1755-3302E/MC | Microchip
U9 | LDL212_DFN6_3X3 | DFN6_3X3MM | 1 | LDL212PUR | STMicroelectronics
X1 | CRYSTAL-3.2-2.5 | CRYSTAL-3.2-2.5 | 1 | 403I35D12M00000 | CTS Components

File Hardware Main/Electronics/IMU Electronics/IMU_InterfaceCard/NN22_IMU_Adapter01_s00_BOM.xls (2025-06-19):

PCBWay Bom Quotation, Product No.:T-1Y54W206116A
Item # | *Designator | *Qty | *Mfg Part # | Description / Value | *Package/Footprint | Mounting Type | *Unit Price(4 sets) | *Total | *Delivery Time | *Actual Purchase Mfg Part # | *PCBWay Note | Customer Reply
1 | LED1 | 1 | LTST-C191KRKT | LED RED CLEAR SMD | LED-0603 | SMD | $0.029 | $0.116
2 | LED2 | 1 | LTST-C191KGKT | LED GREEN CLEAR SMD | LED-0603 | SMD | $0.031 | $0.124
3 | C1, C3, C6, C8, C9, C16, C17, C18, C19, C20, C21, C22, C23, C24 | 14 | GRM155R71H104KE14D | CAP CER 0.1UF 50V X7R 0402『 』0.1u『 』0.1u | 0402-CAP | SMD | $0.014 | $0.784
4 | R1, R2, R10, R16, R24 | 5 | RC0402FR-071K2L | RES 1.2K OHM 1% 1/16W 0402『 』1.2k『 』1.2k | 0402-RES | SMD | $0.004 | $0.080
5 | R3, R4, R5, R6, R7, R8, R9 | 7 | RC0402FR-0710RL | 10 Ohms ±1% 0.063W, 1/16W Chip Resistor 0402 (1005 Metric) Moisture Resistant Thick Film『 』10 | 0402-RES | SMD | $0.004 | $0.112
6 | R12, R15, R17, R18, R19, R25, R26 | 7 | RC0402FR-07100KL | RES 100K OHM 1% 1/16W 0402『 』100k『 』100k | 0402-RES | SMD | $0.003 | $0.084
7 | C2, C7, C10 | 3 | GRM188R6YA106MA73D | CAP CER 10UF 35V X5R 0603『 』10u『 』10u | 0603-CAP | SMD | $0.149 | $1.788
8 | R21, R22, R27, R28 | 4 | RC0402FR-0727RL | RES 27 OHM 1% 1/16W 0402『 』27『 』27 | 0402-RES | SMD | $0.005 | $0.080
9 | C11, C12 | 2 | GCM1555C1H270JA16D | CAP CER 27PF 50V C0G/NP0 0402『 』27p『 』27p | 0402-CAP | SMD | $0.088 | $0.704
10 | R23 | 1 | CRCW040233R0FKEDC | RES 33 OHM 1% 1/16W 0402『 』33『 』33 | 0402-RES | SMD | $0.161 | $0.644
11 | C4, C5, C13, C14, C15 | 5 | CL05A475MP5NRNC | CAP CER 4.7UF 10V X5R 0402『 』4.7u『 』4.7u | 0402-CAP | SMD | $0.027 | $0.540
12 | R20 | 1 | RC0402FR-0782KL | RES 82K OHM 1% 1/16W 0402『 』82k | 0402-RES | SMD | $0.012 | $0.048
13 | U4 | 1 | AP22653AW6-7 | LOAD SWITCH,SOT26,T&R,3K『 』AP2265X_SOT | SOT23-6 | SMD | $0.308 | $1.232
14 | D9, D10 | 2 | BAV70WT1G | DIODE ARRAY GP 100V 200MA SC70-3『 』BAV70W | SOT323 | SMD | $0.095 | $0.760
15 | X1 | 1 | 403I35D12M00000 | CRYSTAL 12.0000MHZ 18PF SMD『 』CRYSTAL-3.2-2.5『 』CRYSTAL-3.2-2.5 | CRYSTAL-3.2-2.5 | SMD | $0.798 | $3.192 | 7-10 Workdays
16 | D1, D2, D3, D4, D5, D6, D7, D8 | 8 | D1213A-02SO-7 | TVS DIODE 3.3VWM 10VC SOT26『 』D1213A-02SO | SOT23-6 | SMD | $0.153 | $4.896
17 | R11, R13, R14 | 3 |  | DNP | 0603-RES | DNP |  |  |  |  | [DNP不要贴];
18 | FID1, FID2, FID3, FID4, FID5, FID6, FID7, FID8 | 8 |  | FIDUCIALUFIDUCIAL | MICRO-FIDUCIAL | DNP |  |  |  |  | [DNP不要贴];
20 | J5 | 1 | SM03B-SRSS-TB | CONN HEADER SMD R/A 3POS 1MM |  | SMD
21 | J3, J4 | 2 |  | M04X2_0.050_SMD_NO_CREAM | M04X2_0.050_SMD_NO_CREAM | DNP |  |  |  |  | [DNP不要贴];
22 | J1 | 1 | 3220-26-0300-00 | CONN HEADER SMD 26POS 1.27MM『 』M13X2_0.050_SHF | M13X2_0.050_SHF | SMD | $2.138 | $8.552 | 7-10 Workdays
23 | J2 | 1 | 15150402601000 | CONN HEADER SMD R/A 40POS 1.27MM『 』M20X2_HARFLEX_M | M20X2_HARFLEX_M | SMD | $6.766 | $27.064 | 7-10 Workdays
24 | U2 | 1 | MCP1755-3302E/MC | IC REG LINEAR 3.3V 300MA 8DFN『 』MCP1755_DFN『 』MCP1755_DFN | DFN8_2X3MM | SMD | $1.096 | $4.384 | 7-10 Workdays
25 | U1 | 1 | SC0914(7) | IC MCU 32BIT EXT MEM 56QFN『 』RP2040『 』RP2040 | QFN-56_EP | SMD | $1.441 | $5.764 | 7-10 Workdays
26 | S1 | 1 | KMR231NG LFS | SWITCH TACTILE SPST-NO 0.05A 32V『 』SWITCH-MOMENTARY-2SMD-3『 』SWITCH-MOMENTARY-2SMD-3 | TACTILE_SWITCH_SMD-3 | SMD | $0.910 | $3.640 |  | KMR231NGLFS
27 | TP5 | 1 |  | TESTPOINT1X01 | 1X01 | DNP |  |  |  |  | [DNP不要贴];
28 | TP4 | 1 |  | TESTPOINTPADSMALL | TESTPAD_SMALL | DNP |  |  |  |  | [DNP不要贴];
29 | TP1, TP2, TP3 | 3 |  | TESTPOINT_ROUND | TESTPAD_ROUND | DNP |  |  |  |  | [DNP不要贴];
30 | J6 | 1 | 10118194-0001LF | CONN RCPT USB2.0 MICRO B SMD R/A『 』USB-MICRO『 』USB-MICRO | USB-MICRO | SMD/PTH | $0.318 | $1.272
31 | U3 | 1 | W25Q16JVUXIQ TR | IC FLASH 16MBIT SPI/QUAD 8USON『 』W25Q_USON『 』W25Q_USON | USON8L-2X3MM | SMD | $0.889 | $3.556 | 7-10 Workdays
32 | U5 | 1 | ISM330DHCXTR | Accelerometer, Gyroscope, Temperature, 6 Axis Sensor I2C, SPI Output | LGA14-L | SMD
 |  |  |  |  |  |  | Component Cost | $69.42

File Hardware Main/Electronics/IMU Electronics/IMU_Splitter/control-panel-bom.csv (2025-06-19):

Reference | Value | Datasheet | Footprint | Qty | DNP
C1 | 10uF | ~ | Capacitor_SMD:C_0805_2012Metric_Pad1.18x1.45mm_HandSolder | 1
C2 | 22uF | ~ | Capacitor_SMD:C_0805_2012Metric_Pad1.18x1.45mm_HandSolder | 1
D1,D2 | LED | ~ | LED_SMD:LED_0805_2012Metric_Pad1.15x1.40mm_HandSolder | 2
J1,J2,J3,J4,J5,J6 | 4P4C | ~ | my_RJ:A-2004-3-4-LP | 6
J7 | 3220-26-0200-00 | ~ | models:SAMTEC_SHF-113-01-L-D-RA | 1
J8 | Conn_01x04 | ~ | Connector_PinHeader_1.27mm:PinHeader_1x04_P1.27mm_Vertical | 1
J9 | Conn_01x05 | ~ | Connector_PinHeader_2.54mm:PinHeader_1x05_P2.54mm_Vertical | 1
R1 | 1.5k | ~ | Resistor_SMD:R_0805_2012Metric_Pad1.20x1.40mm_HandSolder | 1
R2 | 510 | ~ | Capacitor_SMD:C_0805_2012Metric_Pad1.18x1.45mm_HandSolder | 1
U1 | AP2114H-3.3TRG1 | https://www.diodes.com/assets/Datasheets/AZ1117.pdf | Package_TO_SOT_SMD:SOT-223-3_TabPin2 | 1

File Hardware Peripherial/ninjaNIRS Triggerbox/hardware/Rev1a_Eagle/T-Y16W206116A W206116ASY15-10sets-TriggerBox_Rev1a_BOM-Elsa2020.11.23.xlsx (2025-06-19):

 |  |  | ninjaNIRS_TriggerBox_Rev1a
Item # | *Designator | *Qty | Manufacturer | *Mfg Part # | Description / Value | *Package/Footprint | Type | Your Instructions / Notes | Unit Price 10sets | Total Price | Note
1 | R1, R16, R18, R20, R22 | 5 | Yageo | RC1206FR-07100RL | RES SMD 100 OHM 1% 1/4W 1206 | 1206 | SMD |  | $0.022 | $1.100
2 | C2, C3, C10 | 3 | Kemet | C0805C104M3RACTU | CAP CER 0.1UF 25V X7R 0805 | 0805 | SMD |  | $0.022 | $0.660
3 | R3, R4, R5, R6, R7, R8, R9, R10 | 8 | Yageo | RC1206JR-0710KL | RES SMD 10K OHM 5% 1/4W 1206 | 1206 | SMD |  | $0.022 | $1.760
4 | C1, C4, C9 | 3 | Samsung | CL32B106KOULNNE | CAP CER 10UF 16V X7R 1210 | 1206 | SMD |  | $0.141 | $4.230 | According to part number, correct package is 1210, not 1206, ok? | OK
5 | R2, R15, R17, R19, R21, R23, R24, R25, R26 | 9 | Yageo | RC1206JR-071KL | RES SMD 1K OHM 5% 1/4W 1206 | 1206 | SMD |  | $0.022 | $1.980
6 | R11, R12, R13, R14 | 4 | Stackpole | RMCF1206FT39R0 | RES 39 OHM 1% 1/4W 1206 | 1206 | SMD |  | $0.022 | $0.880
7 | C5, C6, C7, C8 | 4 | Kemet | C0805C473K3RACTU | CAP CER 0.047UF 25V X7R 0805 | 1206 | SMD |  | $0.043 | $1.720 | According to part number, correct package is 0805, not 1206, OK? | OK
8 | JP2 | 0 |  |  | Antenna |  |  | DNP |  | $0.000 | DNP
9 | JP1 | 1 | Mill-Max | 801-43-007-20-001000 | CONN RCPT 7POS 0.1 GOLD PCB R/A |  | PTH |  |  |  | Not available, out of stock. Plz recommend replacements. | Please use Sullins PPTC071LGBN-RC
10 | S2, S3, S4, S5 | 4 | E-switch | 800BWSP9SM6RE | SWITCH PUSH SPST-NO 0.4VA 20V |  | SMD |  | $6.386 | $255.440 | 7-10work days | How come it is this expensive? Price at Digikey is $4.14
11 | LED2, LED3, LED4, LED5 | 4 | Kingbright | APA1606QBC/D | LED BLUE CLEAR CHIP SMD R/A |  | SMD |  | $0.424 | $16.960 | 5-7work days
12 | LED1 | 1 | Lite-on | LTST-C191KGKT | LED GREEN CLEAR SMD | 0603 | SMD |  | $0.080 | $0.800
13 | X1 | 1 | Hirose | UX60A-MB-5ST | CONN RCPT USB2.0 MINI B SMD R/A |  | SMD |  | $1.247 | $12.470
14 | T1, T2, T3, T4, T5, T6, T7, T8 | 8 | Diodes | MMBT3906-7-F | TRANS PNP 40V 0.2A SOT23-3 | SOT 23-3 | SMD |  | $0.037 | $2.960
15 | IC1 | 1 | Texas Instruments | SN74HCS08QDRQ1 | IC LOGIC GATE | SO-14 | SMD |  | $0.507 | $5.070 | 5-7work days
16 | X2, X3, X4, X5 | 4 | TE Connectivity | 5227161-9 | CONN BNC JACK R/A 50 OHM PCB |  | PTH |  | $4.262 | $170.480 | 5-7work days | How come it is this expensive? Price at Digikey is $3.18
 |  |  |  |  |  |  |  |  |  | 476.51
Need a quick and accurante quote? Need an efficient production? Please read SMT Ordering Necessary Files & Info in 1 minute. Thank you very much!
Click for Instructions on How to Create a BOM (https://www.pcbway.com/blog/PCB_Assembly/How_to_Build_a_BOM__Bill_Of_Materials_.html)
 |  |  |  |  |  |  |  |  | we quoted according to the list of *Mfg Part #, all OK? |  |  | OK

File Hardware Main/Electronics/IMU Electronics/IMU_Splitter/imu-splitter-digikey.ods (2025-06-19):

 | Boards: | 3
# | Reference | Qty | Value | Footprint | DNP | CatNo | MfgNo | OrderQty
1 | C1 | 1 | 10uF | Capacitor_SMD:C_0805_2012Metric_Pad1.18x1.45mm_HandSolder |  | 1276-1096-1-ND | CL21A106KOQNNNE | 3
2 | C2 | 1 | 22uF | Capacitor_SMD:C_0805_2012Metric_Pad1.18x1.45mm_HandSolder |  | 1276-6526-1-ND | CL21A226KOQNNNE | 3
3 | D1, D2 | 2 | LED | LED_SMD:LED_0805_2012Metric_Pad1.15x1.40mm_HandSolder |  | 350-5973006607FCT-ND | 5973006607F | 6
4 | J1, J2, J3, J4, J5, J6 | 6 | 4P4C | my_RJ:A-2004-3-4-LP |  | AE10381-ND | A-2004-3-4-LP-N-R | 18
5 | J7 | 1 | SHF-113-01-L-D-SM | models:SAMTEC_SHF-113-01-L-D-RA |  | SAM10712-ND | SHF-113-01-L-D-SM | 3
6 | J8 | 1 | Conn_01x04 | Connector_PinHeader_1.27mm:PinHeader_1x04_P1.27mm_Vertical |  | SAM10242-ND | TMS-104-01-G-S | 3
7 | J9 | 1 | Conn_01x05 | Connector_PinHeader_2.54mm:PinHeader_1x05_P2.54mm_Vertical |  | 609-3462-ND | 68000-105HLF | 3
8 | R1 | 1 | 1.5k | Resistor_SMD:R_0805_2012Metric_Pad1.20x1.40mm_HandSolder |  | 311-1.50KCRCT-ND | RC0805FR-071K5L | 3
9 | R2 | 1 | 510 | Capacitor_SMD:C_0805_2012Metric_Pad1.18x1.45mm_HandSolder |  | 311-510CRCT-ND | RC0805FR-07510RL | 3
10 | U1 | 1 | AZ1117-3.3 | Package_TO_SOT_SMD:SOT-223-3_TabPin2 |  | 31-AZ1117CH2-3.3TRG1CT-ND | AZ1117CH2-3.3TRG1 | 3
11 | RJ-J1 | 1 |  |  |  | AE10381-ND | A-2004-3-4-LP-N-R | 3
12 | RJ-J2 | 1 |  |  |  | SAM10717-ND | SLM-104-01-G-S | 3
13 | ISP-J1 | 1 |  |  |  | 2057-PH2-06-UA-ND | PH2-06-UA | 3
14 | ISP-J2 | 1 |  |  |  | 2073-BC020-06-A-0200-0300-L-D-ND | BC020-06-A-0200-0300-L-D | 3
 |  |  |  |  |  |  |  | 0
 |  |  |  |  |  |  |  | 0

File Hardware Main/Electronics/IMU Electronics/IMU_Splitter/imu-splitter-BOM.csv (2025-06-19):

Reference | Value | Qty | CatNo | MfgNo
C1 | 10uF | 1 | 1276-1096-1-ND | CL21A106KOQNNNE
C2 | 22uF | 1 | 1276-6526-1-ND | CL21A226KOQNNNE
D1,D2 | LED | 2 | 350-5973006607FCT-ND | 5973006607F
J1,J2,J3,J4,J5,J6 | 4P4C | 6 | AE10381-ND | A-2004-3-4-LP-N-R
J7 | 3220-26-0200-00 | 1 | 1175-1640-ND | 3220-26-0200-00
J8 | Conn_01x04 | 1 | SAM10242-ND | TMS-104-01-G-S
J9 | Conn_01x05 | 1 | 609-3462-ND | 68000-105HLF
J10 | 3221-26-0100-00 | 1 | 1175-1745-ND | 3221-26-0100-00
N1 | 1551T | 1
R1 | 1.5k | 1 | 311-1.50KCRCT-ND | RC0805FR-071K5L
R2 | 510 | 1 | 311-510CRCT-ND | RC0805FR-07510RL
U1 | AP2114H-3.3TRG1 | 1 | AP2114H-3.3TRG1DICT-ND | AZ1117CH-3.3TRG1

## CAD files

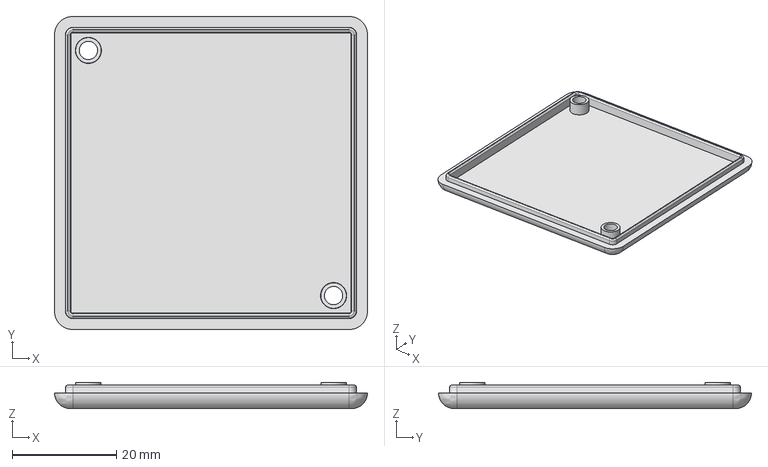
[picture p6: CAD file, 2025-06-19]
Hardware Main/Electronics/IMU Electronics/IMU_Splitter/3D/1551T_Lid_transparent.FCStd
60.0 x 60.0 x 5.00 mm

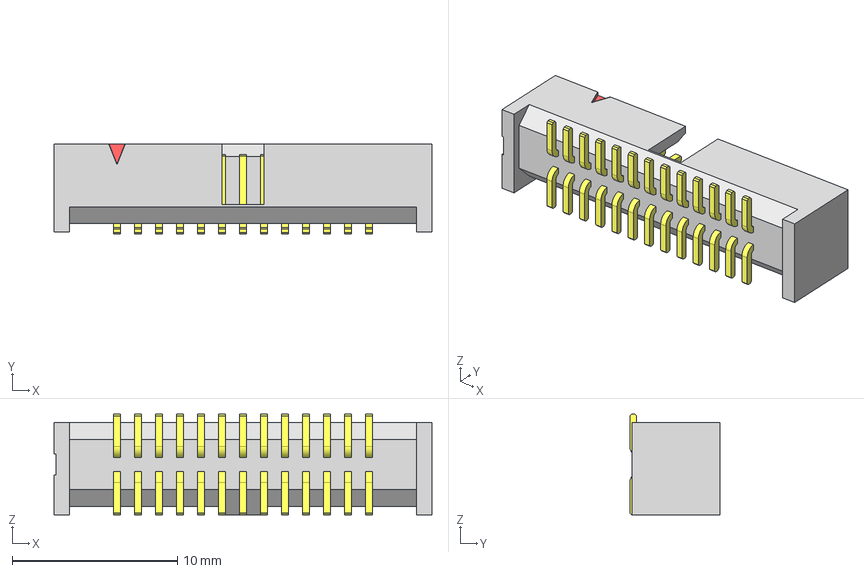
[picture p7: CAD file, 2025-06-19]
Hardware Main/Electronics/IMU Electronics/IMU_Splitter/models/SHF-113-01-L-D-SM.step
22.9 x 5.46 x 6.10 mm
T-1S71-02-13-D-SM
SHF-First_Position_Indicator
SHF-113-01-D_header

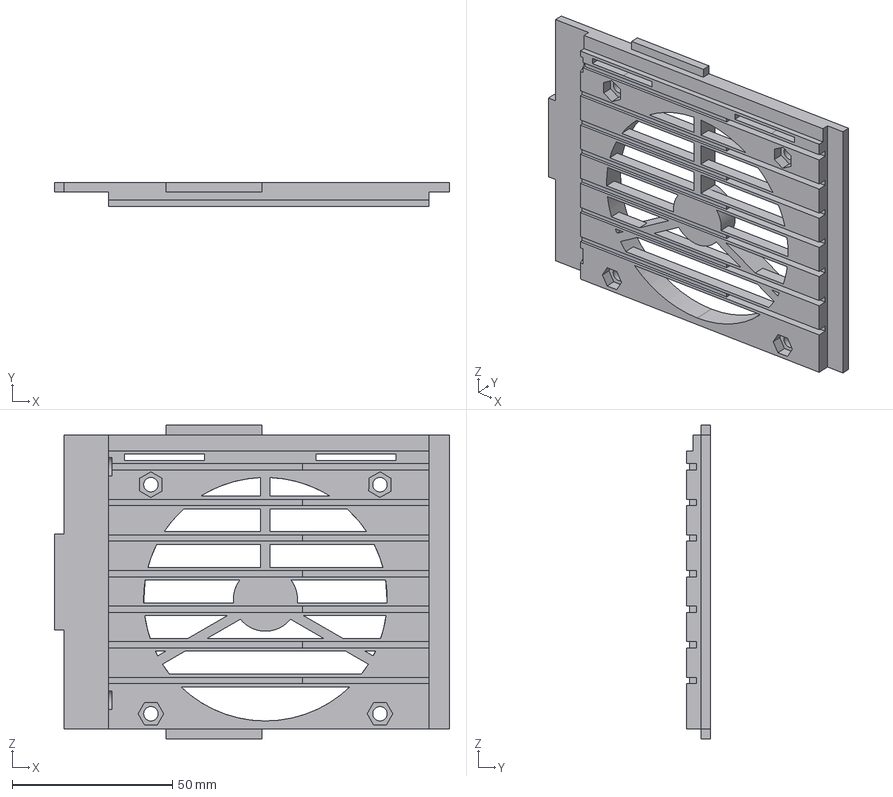
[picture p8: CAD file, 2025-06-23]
Hardware Mechanical/ninjaCasing/SidePanel_Right.step
123.3 x 7.47 x 97.9 mm

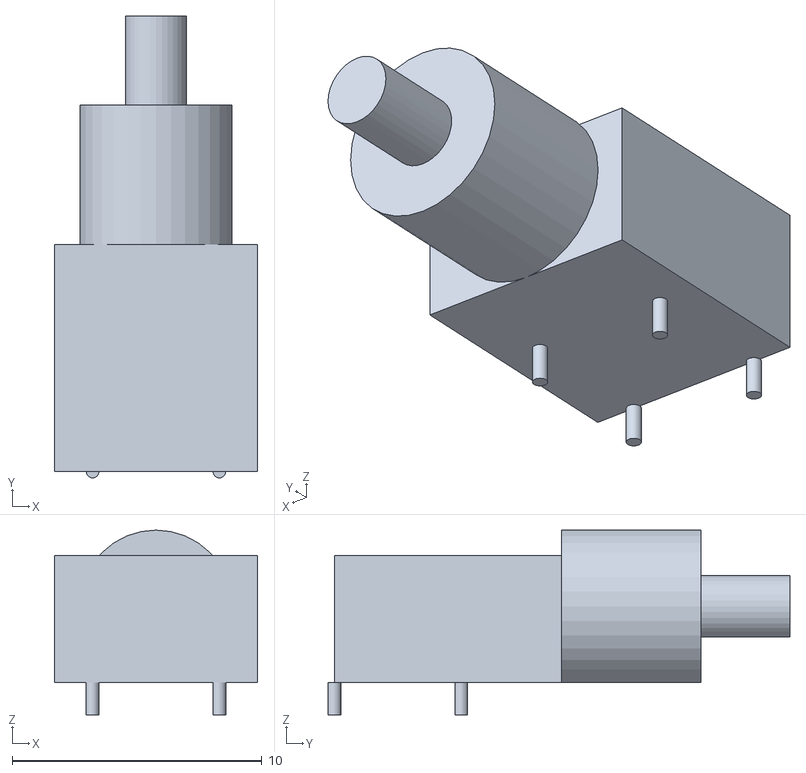
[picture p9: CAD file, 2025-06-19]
Hardware Peripherial/ninjaNIRS Triggerbox/hardware/Rev2_KiCAD/3D/sw_800.stl
8.13 x 18.5 x 7.40

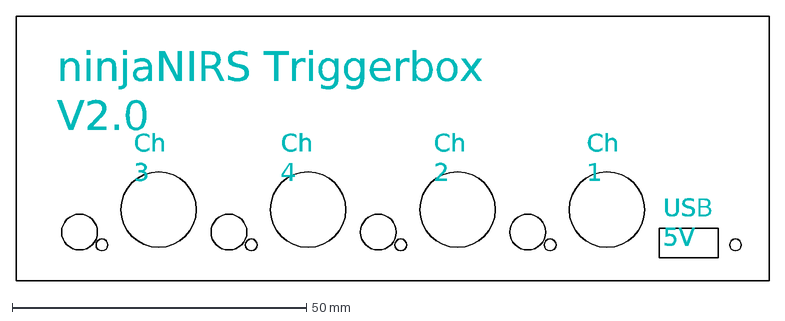
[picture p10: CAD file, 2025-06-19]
Hardware Peripherial/ninjaNIRS Triggerbox/hardware/Rev2_KiCAD/panel/panel_only.dxf
ninjaNIRS Triggerbox V2.0
Ch 1
Ch 2
Ch 4
Ch 3
USB 5V

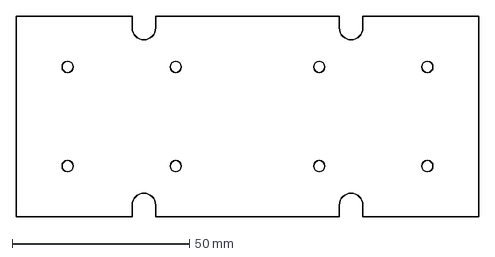
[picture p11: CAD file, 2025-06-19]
Hardware Peripherial/ninjaNIRS Triggerbox/hardware/Rev2_KiCAD/trigger-board/hammond_pcb.dxf
130.7 x 56.6 mm

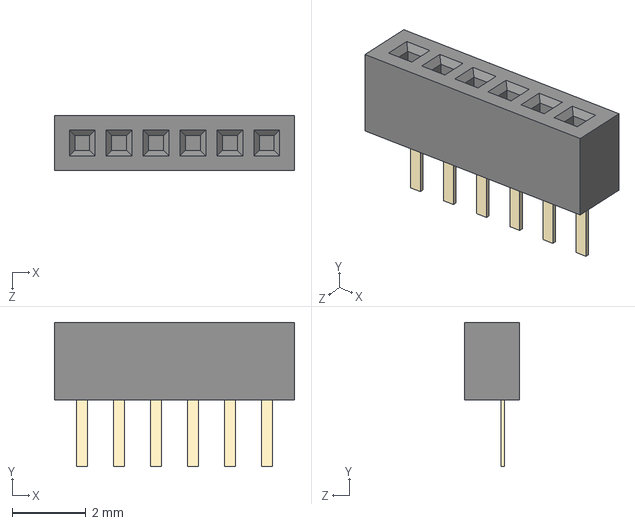
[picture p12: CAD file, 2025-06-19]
IMU-bundle/ninjanirs-imu-main/KiCAD/(Delete) imu-board/models/BC065-06-A-L-D.STEP
6.50 x 3.90 x 1.50 mm
BC065-xxx body_06
pin^BC065- xxxx Ass x 6

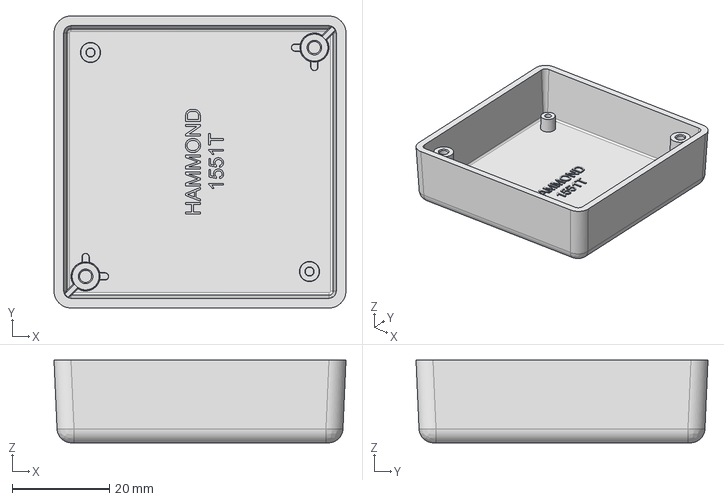
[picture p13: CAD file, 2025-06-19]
IMU-bundle/ninjanirs-imu-main/KiCAD/(Delete) imu-splitter/3D/1551T_Box.step
60.0 x 60.0 x 17.0 mm

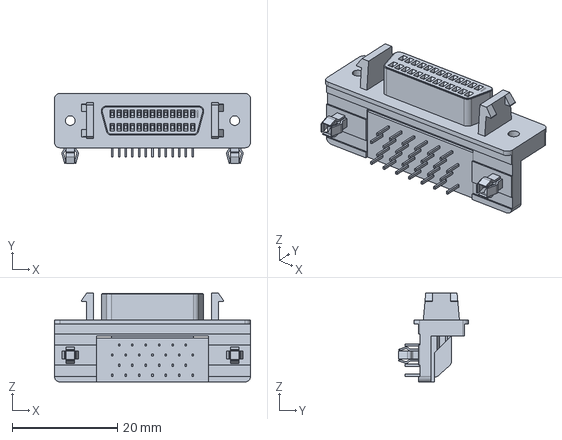
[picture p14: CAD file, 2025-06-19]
IMU-bundle/ninjanirs-imu-main/KiCAD/(Delete) imu-splitter/models/c-5787082-2-a-3d.stp
37.2 x 13.3 x 16.9 mm

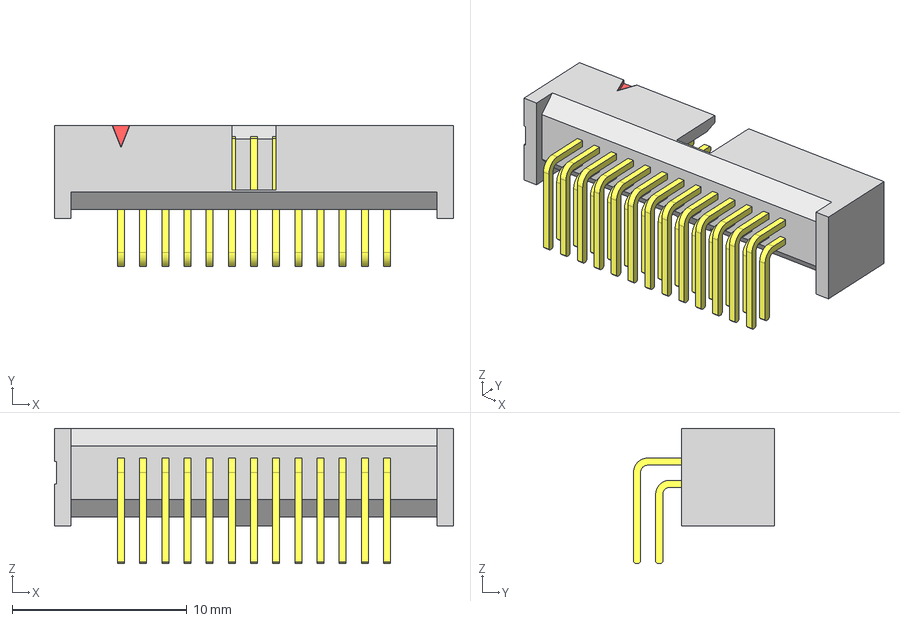
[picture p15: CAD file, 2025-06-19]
Hardware Main/Electronics/IMU Electronics/IMU_Splitter/models/SHF-113-01-L-D-RA.step
22.9 x 8.08 x 7.75 mm
T-1S71-02-13-D-RA
SHF-First_Position_Indicator
SHF-113-01-D_header

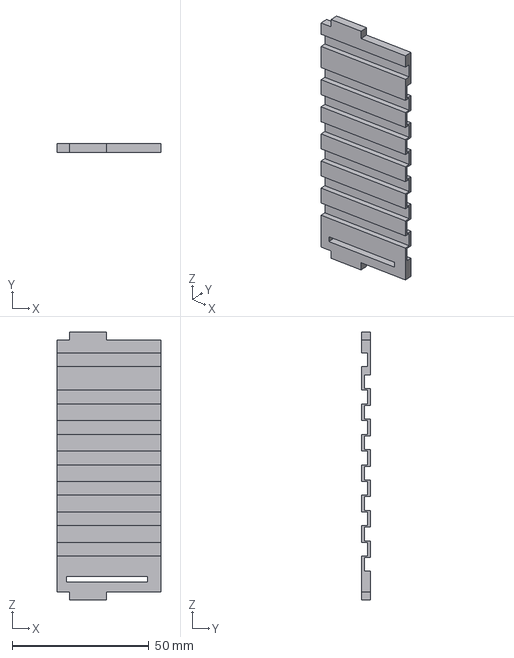
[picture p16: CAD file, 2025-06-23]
Hardware Mechanical/ninjaCasing/SplitterBoard_Support_A.step
38.0 x 3.17 x 97.9 mm

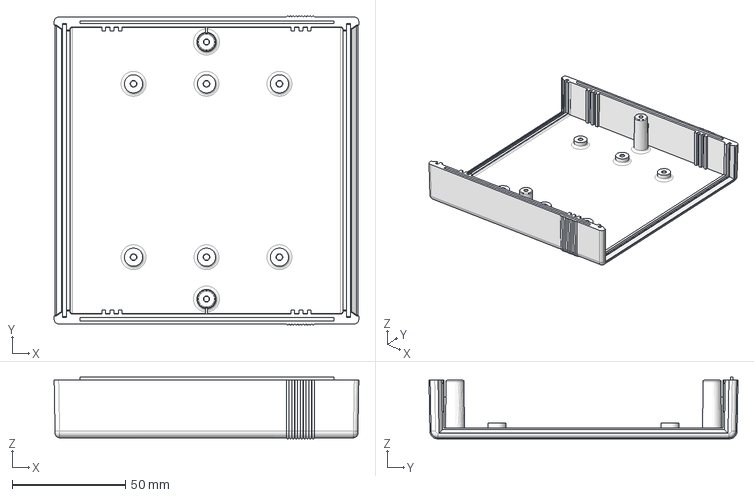
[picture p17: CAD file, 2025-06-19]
Hardware Peripherial/ninjaNIRS Triggerbox/hardware/Rev2_KiCAD/3D/1598B Top.stp
134.3 x 136.2 x 27.2 mm

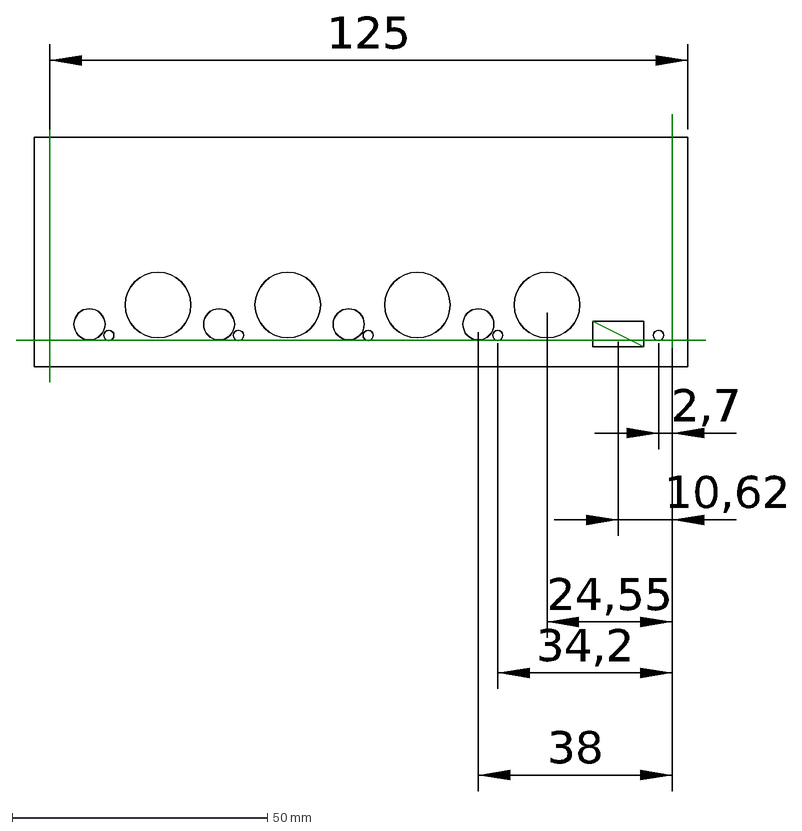
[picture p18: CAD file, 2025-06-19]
Hardware Peripherial/ninjaNIRS Triggerbox/hardware/Rev2_KiCAD/panel/panel.dxf
125
2,7
10,62
24,55
34,2
38

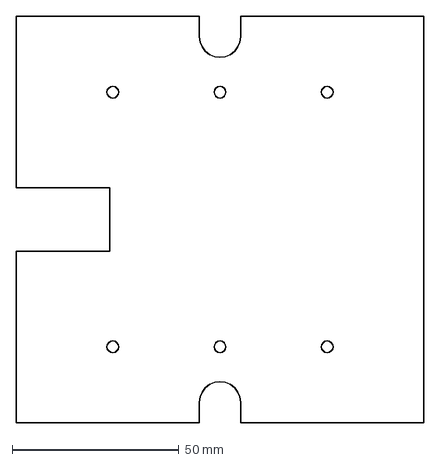
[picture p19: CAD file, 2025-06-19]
Hardware Peripherial/ninjaNIRS Triggerbox/hardware/Rev2_KiCAD/trigger-board/Hammond_1598B.dxf
122.3 x 122.0 mm

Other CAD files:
IMU-bundle/ninjanirs-imu-main/Adapter/outline.dxf
IMU-bundle/ninjanirs-imu-main/KiCAD/(Delete) imu-board/models/ATTINY10-MAHR.step
IMU-bundle/ninjanirs-imu-main/KiCAD/(Delete) imu-splitter/3D/1551TGY.stp
Hardware Main/Electronics/IMU Electronics/IMU_Splitter/3D/A-2004-3-4.scad
IMU-bundle/ninjanirs-imu-main/KiCAD/(Delete) imu-splitter/3D/A-2004-3-4.scad
Hardware Peripherial/ninjaNIRS Triggerbox/hardware/Rev2_KiCAD/3D/PCB_BNC.scad
Hardware Peripherial/ninjaNIRS Triggerbox/hardware/Rev2_KiCAD/3D/sw_800.scad
Hardware Main/Electronics/IMU Electronics/IMU_Splitter/3D/1551T.dxf
Hardware Main/Electronics/IMU Electronics/IMU_Splitter/3D/1551TGY.stp
Hardware Main/Electronics/IMU Electronics/IMU_Splitter/3D/1551T_Lid.step
Hardware Main/Electronics/IMU Electronics/IMU_Splitter/3D/1551T_Lid_trans.step
Hardware Main/Electronics/IMU Electronics/IMU_Splitter/3D/A-2004-3-4-Group.step
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

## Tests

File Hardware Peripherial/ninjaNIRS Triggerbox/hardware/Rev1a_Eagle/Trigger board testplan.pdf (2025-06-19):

Testing ninjaNIRS Rx and Tx trigger board

1. Connect a mini-USB cable to the trigger board and any USB 5V power supply.
a. Check whether the green power on LED lights up
2. Connect the Qiachip Tx trigger board as shown in Figure 1.
3. Supply the Qiachip Tx trigger pcb with +3-5V and GND or connect it to and supply via ninjaNIRS via adapter board.
4. One by another, press each TRIG 1 – TRIG 4 button.
a. Check whether the corresponding blue Tx LED lights up when button is pressed
b. Check whether the red Tx trigger LED on the Qiachip Tx board lights up when button is pressed.
c. Check whether the red Rx trigger LED on the Qiachip Rx board lights up when button is pressed
5. One by another, connect a BNC cable to each TRIG 1 – TRIG 4 BNC connector and generate a High – Low transition using a signal Generator and TTL levels.
a. Check whether the corresponding blue Tx LED, the red Qiachip Tx LED and the red Qiachip Rx LED lights up whenever the BNC signal level is low.

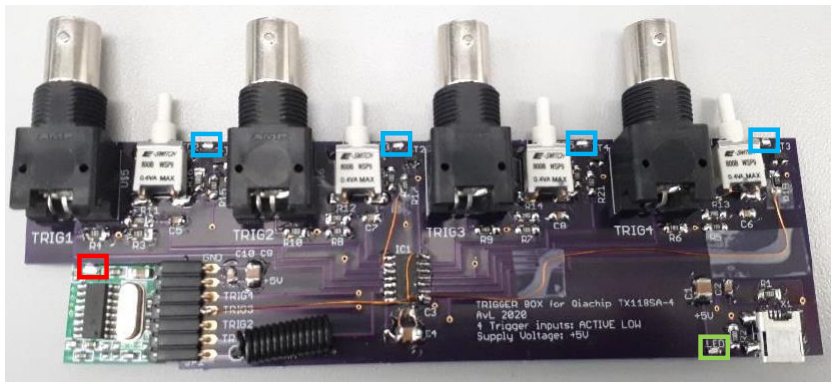
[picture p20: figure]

Figure 1: Tx Trigger Board (v1.0), with Qiachip Tx trigger board connected. Please note Rev 1.1 looks slightly different

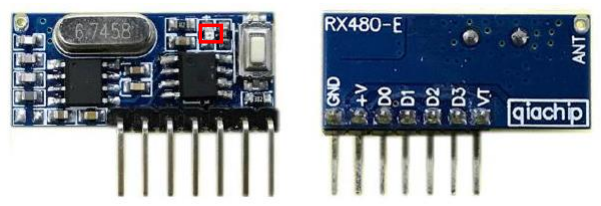
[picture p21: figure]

Figure 2: Qiachip Rx trigger board

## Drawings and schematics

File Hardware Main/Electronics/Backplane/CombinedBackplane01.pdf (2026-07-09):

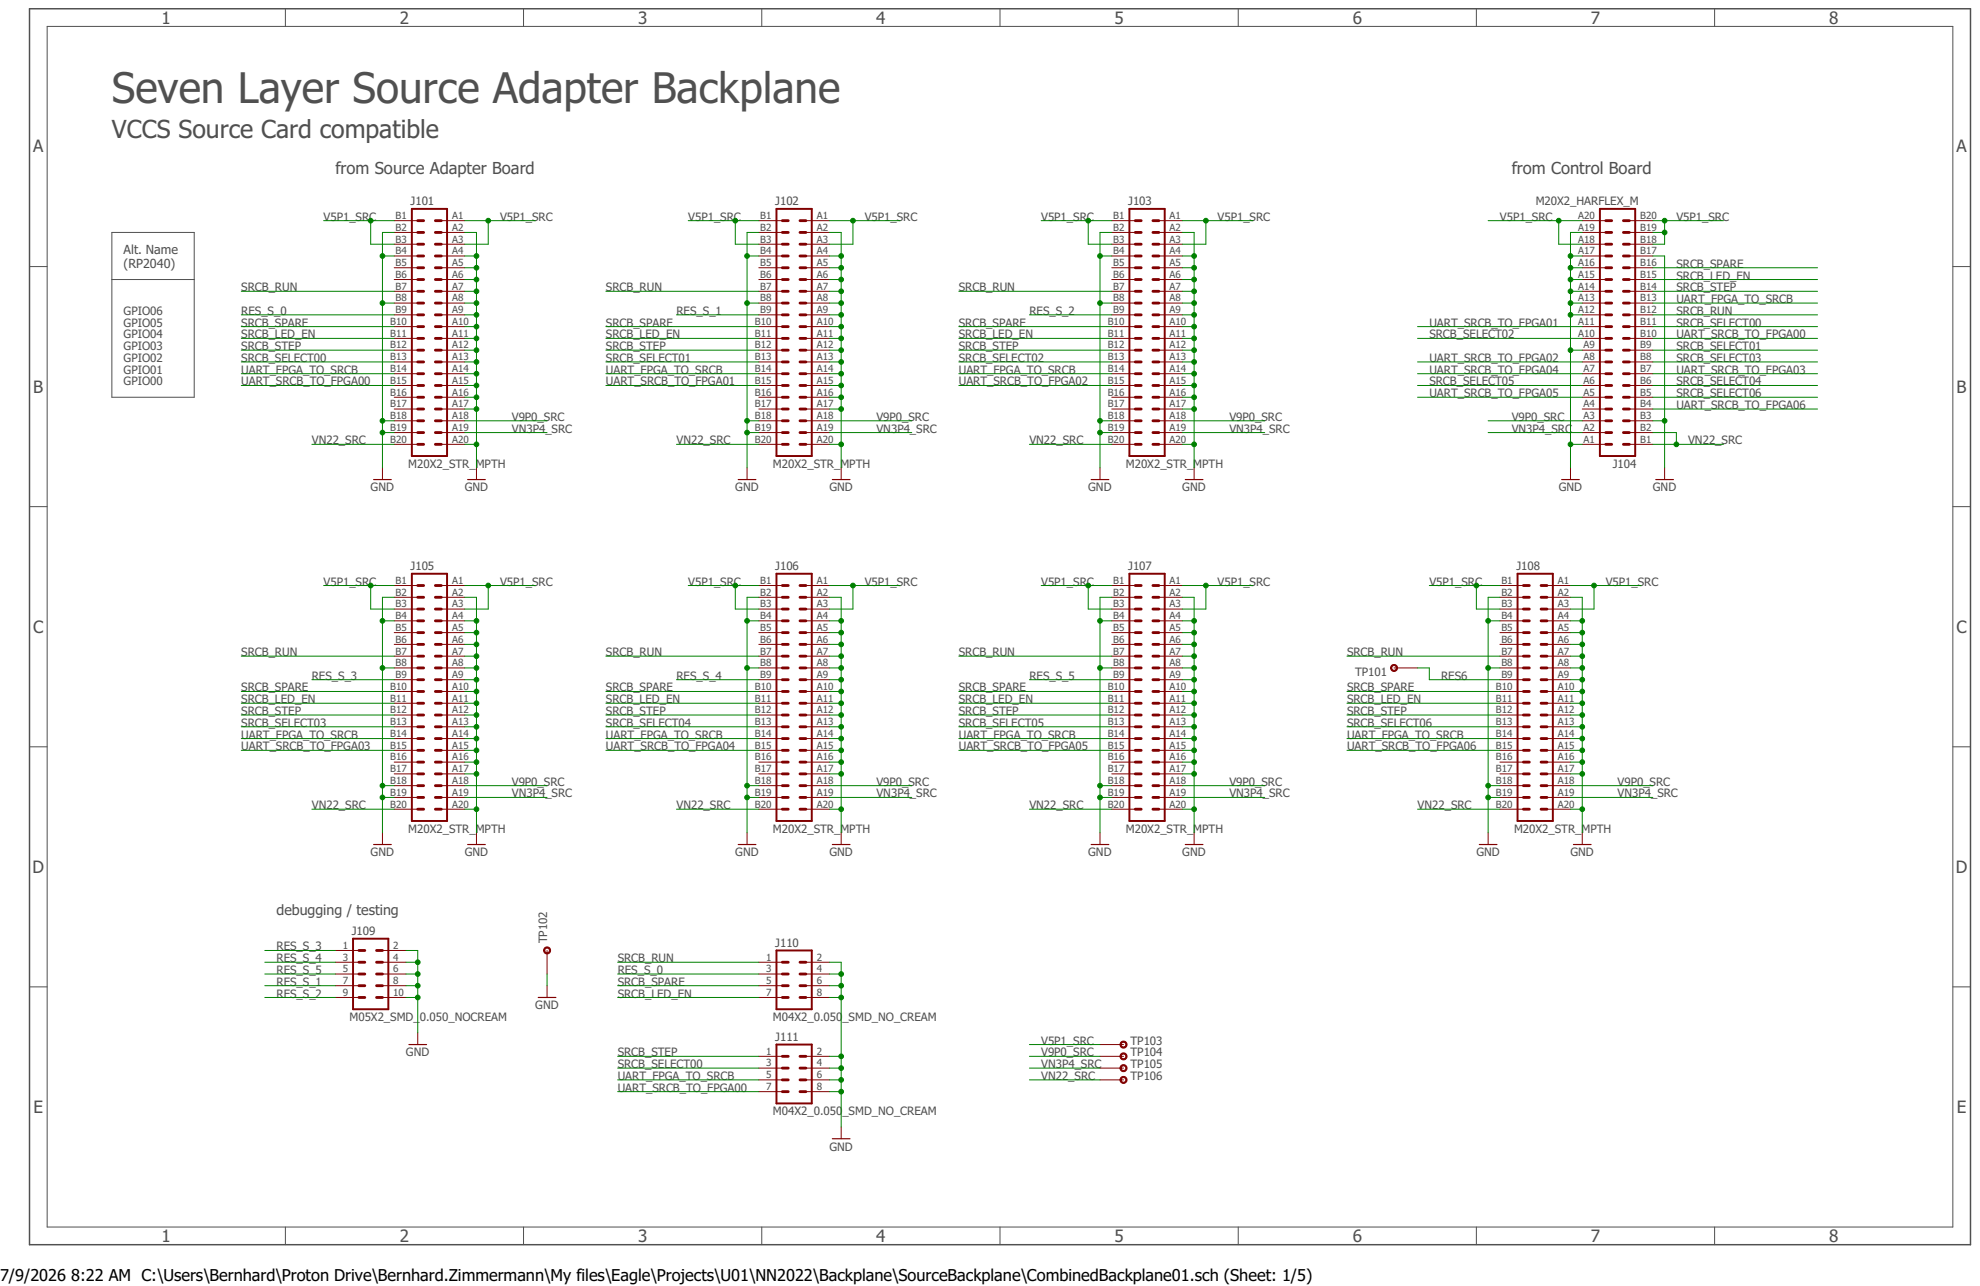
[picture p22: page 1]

Seven Layer Source Adapter Backplane

VCCS Source Card compatible

7/9/2026 8:22 AM C:\Users\Bernhard\Proton Drive\Bernhard.Zimmermann\My files\Eagle\Projects\U01\NN2022\Backplane\SourceBackplane\CombinedBackplane01.sch (Sheet: 1/5)

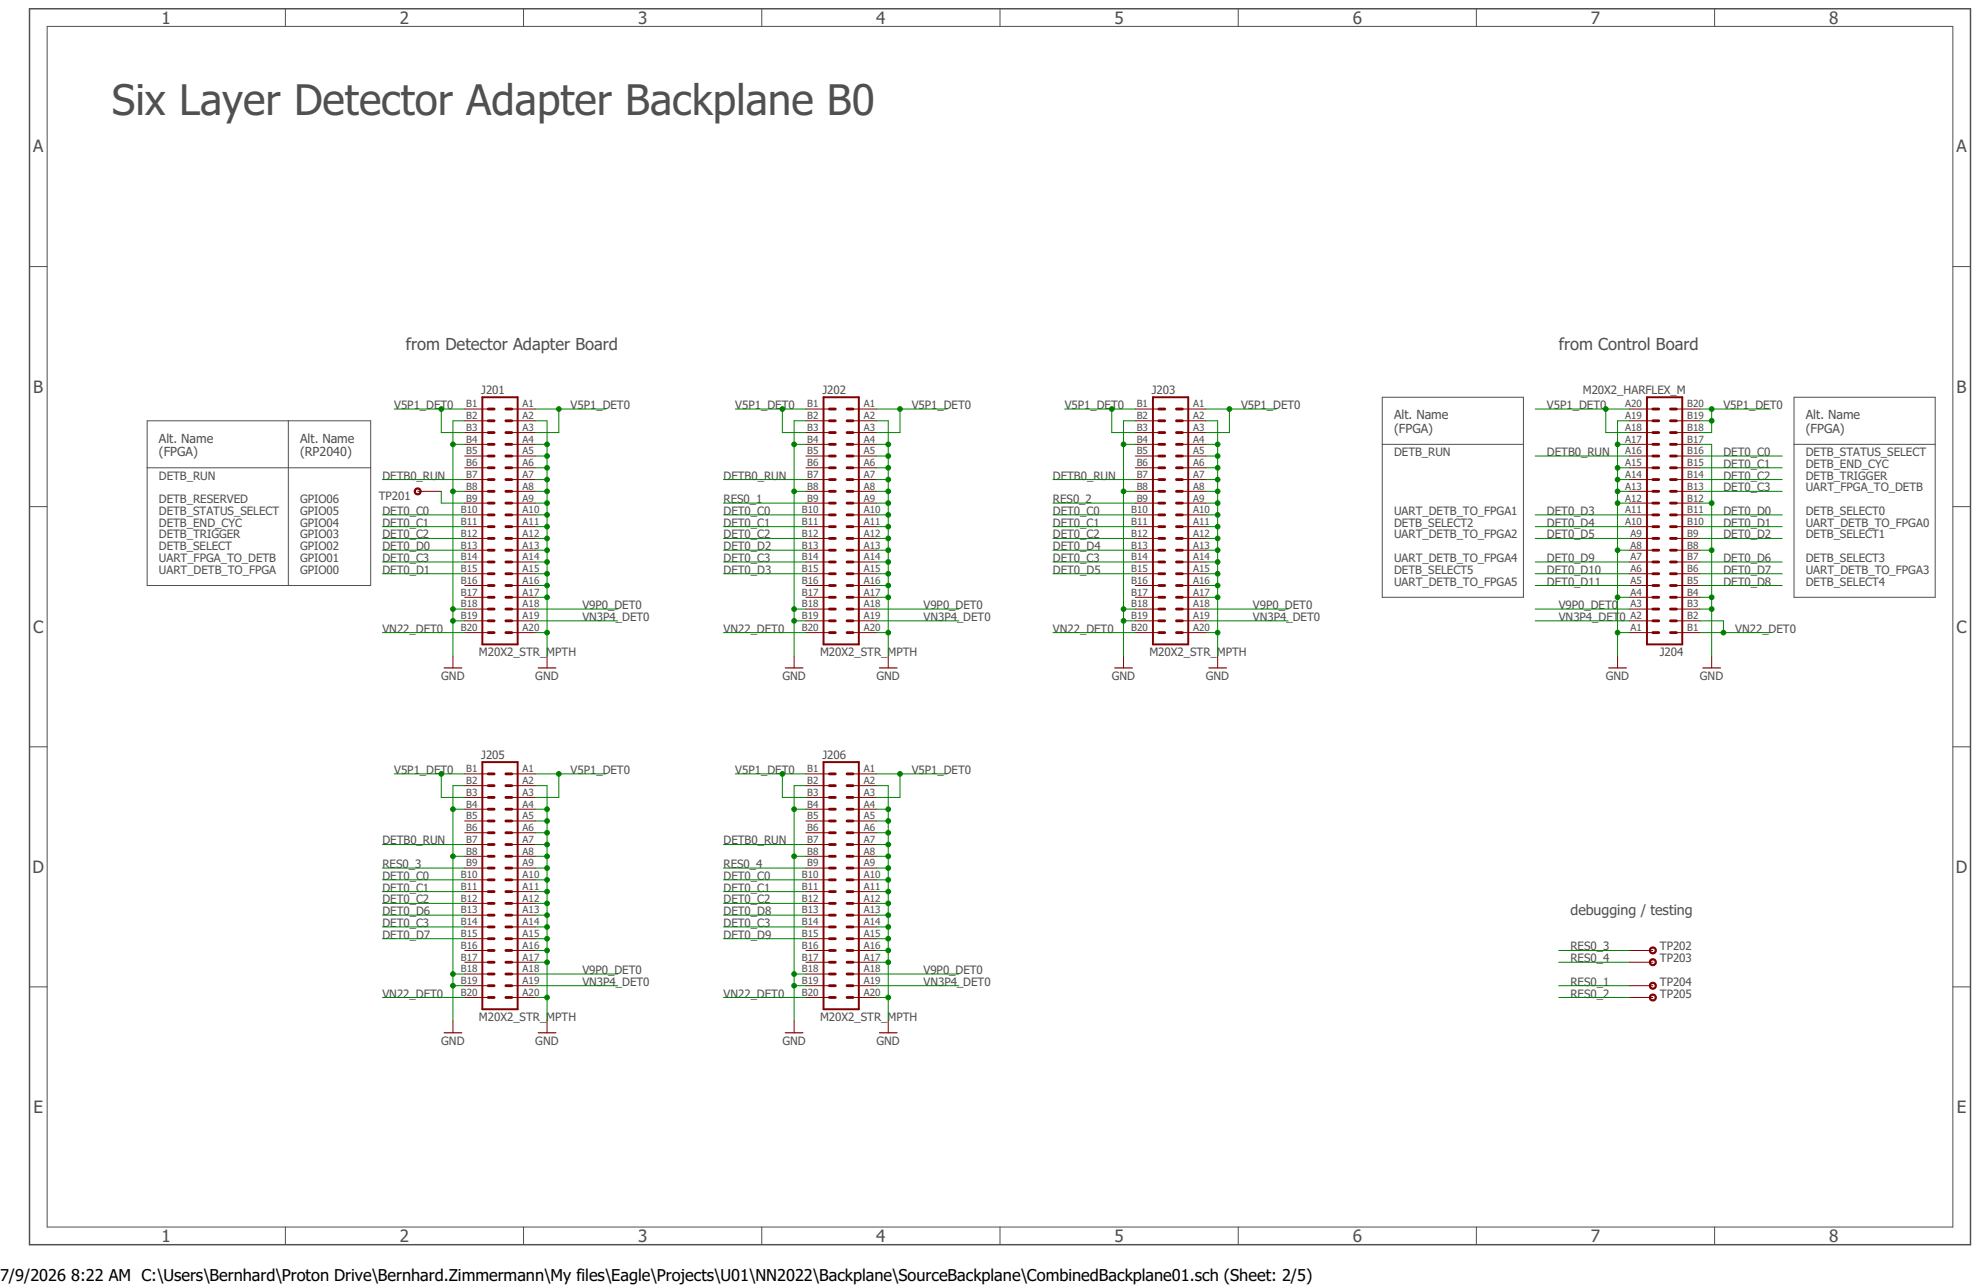
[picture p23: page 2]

Six Layer Detector Adapter Backplane B0

Alt. Name (FPGA) | Alt. Name (RP2040)

DETB_RUN DETB_RESERVED DETB_STATUS_SELECT DETB_END_CYC DETB_TRIGGER DETB_SELECT UART_FPGA_TO_DETB UART_DETB_TO_FPGA | GPIO06 GPIO05 GPIO04 GPIO03 GPIO02 GPIO01 GPIO00

7/9/2026 8:22 AM C:\Users\Bernhard\Proton Drive\Bernhard.Zimmermann\My files\Eagle\Projects\U01\NN2022\Backplane\SourceBackplane\CombinedBackplane01.sch (Sheet: 2/5)

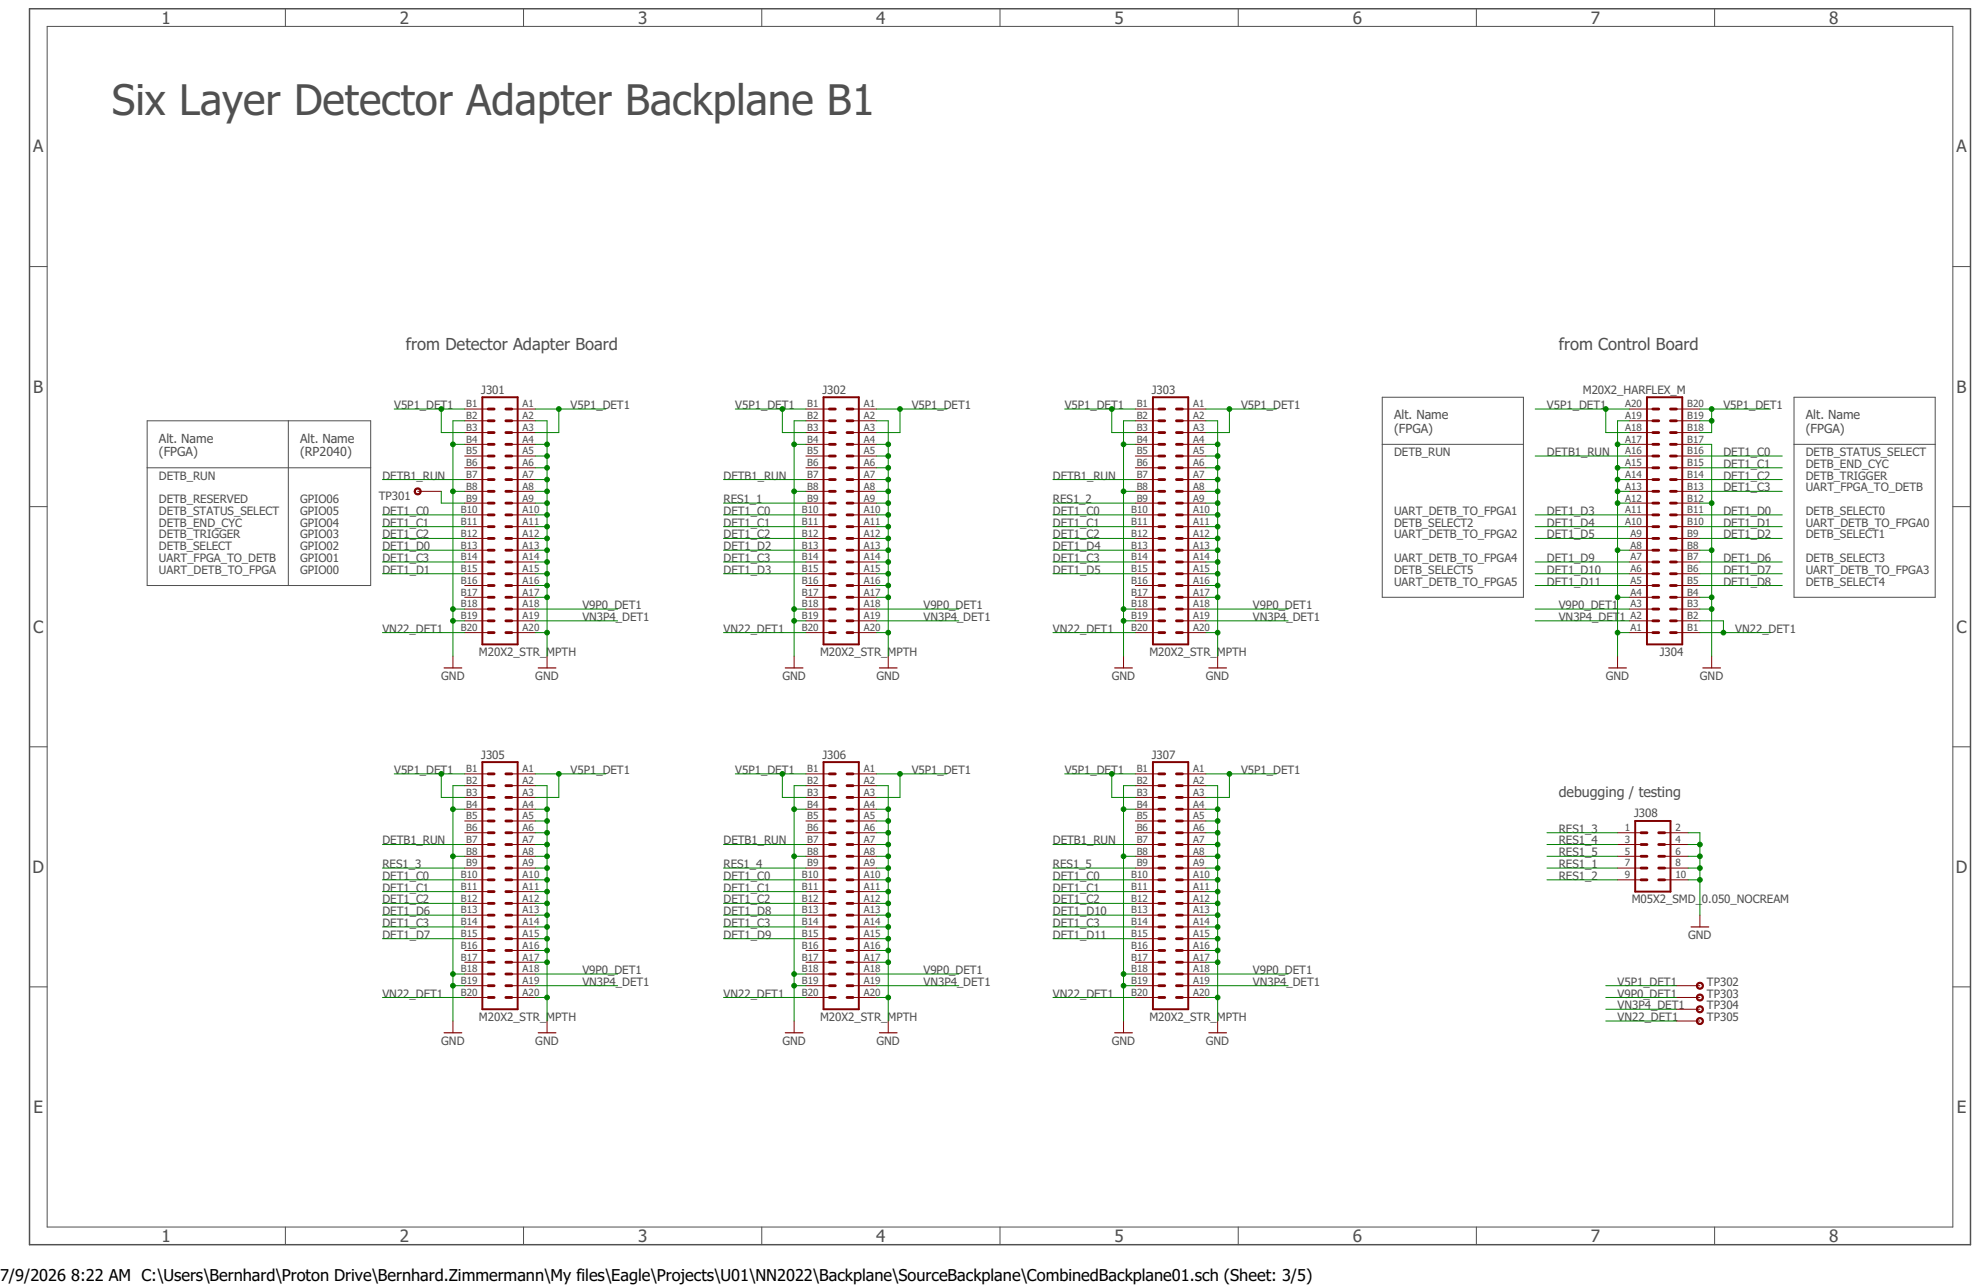
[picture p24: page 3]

Six Layer Detector Adapter Backplane B1

Alt. Name (FPGA) | Alt. Name (RP2040)

DETB_RUN DETB_RESERVED DETB_STATUS_SELECT DETB_END_CYC DETB_TRIGGER DETB_SELECT UART_FPGA_TO_DETB UART_DETB_TO_FPGA | GPIO06 GPIO05 GPIO04 GPIO03 GPIO02 GPIO01 GPIO00

7/9/2026 8:22 AM C:\Users\Bernhard\Proton Drive\Bernhard.Zimmermann\My files\Eagle\Projects\U01\NN2022\Backplane\SourceBackplane\CombinedBackplane01.sch (Sheet: 3/5)

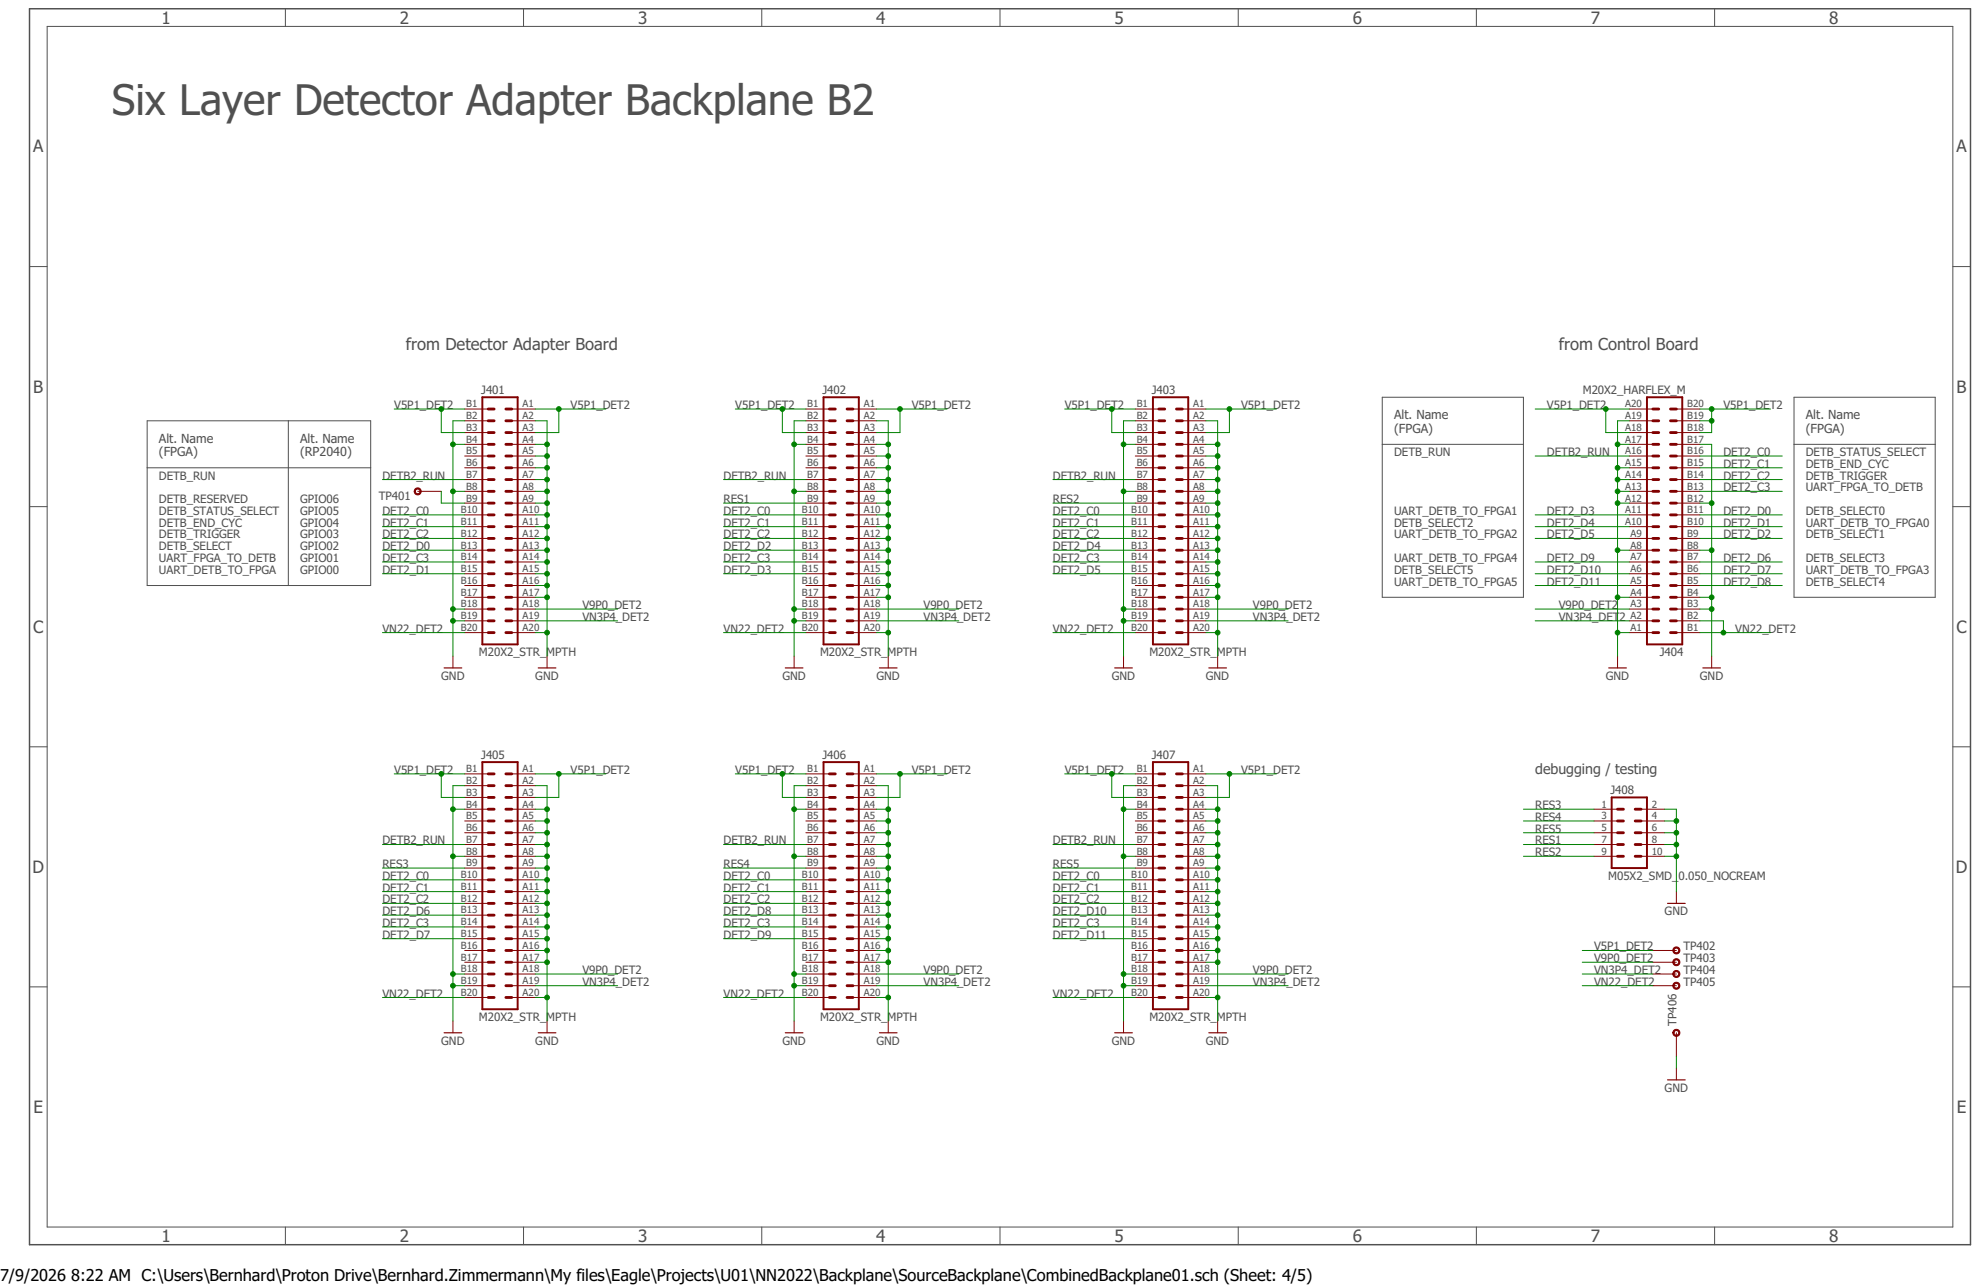
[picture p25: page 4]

Six Layer Detector Adapter Backplane B2

Alt. Name (FPGA) | Alt. Name (RP2040)

DETB_RUN DETB_RESERVED DETB_STATUS_SELECT DETB_END_CYC DETB_TRIGGER DETB_SELECT UART_FPGA_TO_DETB UART_DETB_TO_FPGA | GPIO06 GPIO05 GPIO04 GPIO03 GPIO02 GPIO01 GPIO00

7/9/2026 8:22 AM C:\Users\Bernhard\Proton Drive\Bernhard.Zimmermann\My files\Eagle\Projects\U01\NN2022\Backplane\SourceBackplane\CombinedBackplane01.sch (Sheet: 4/5)

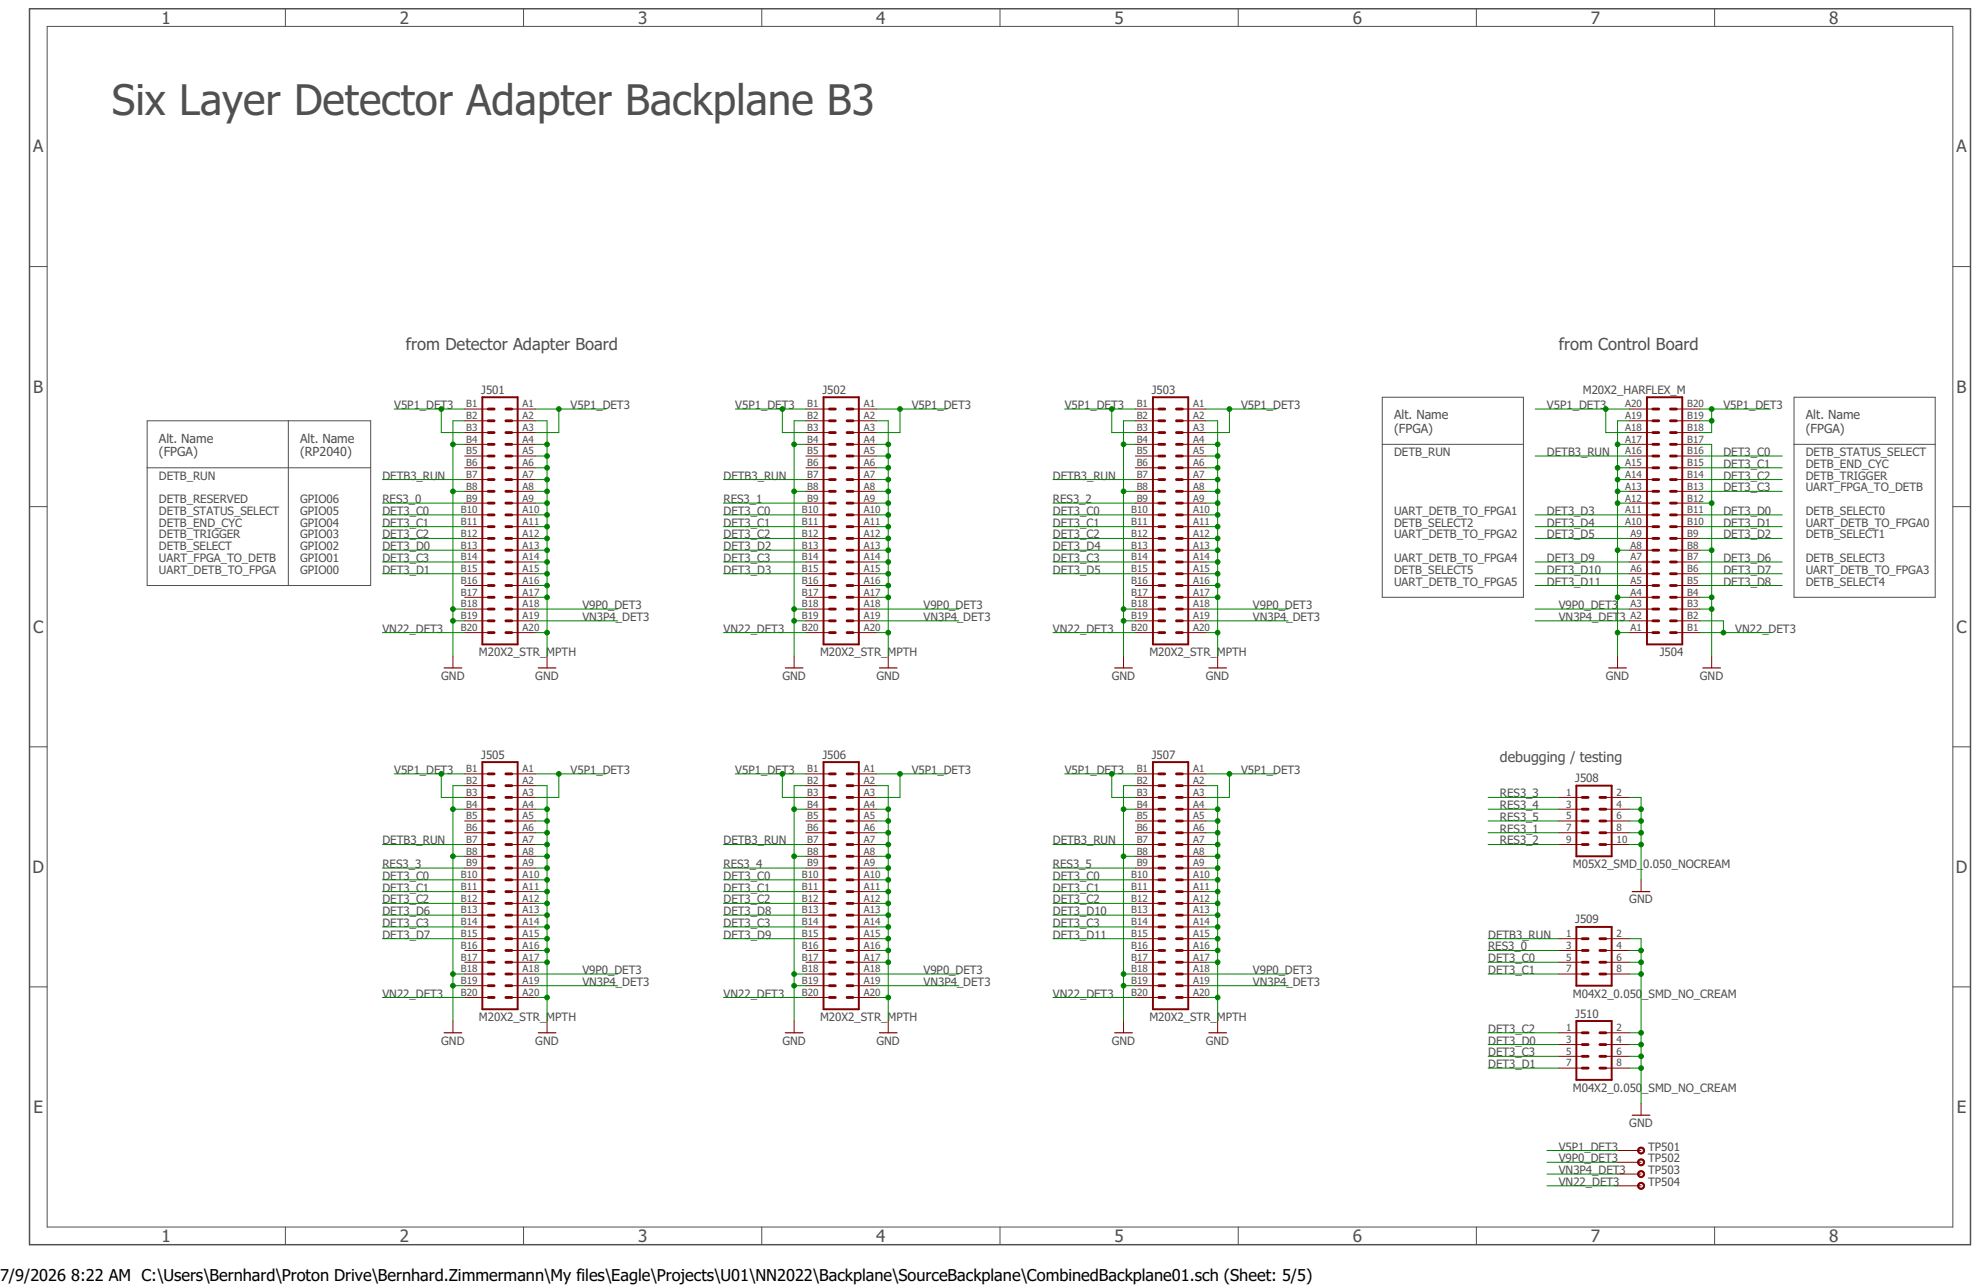
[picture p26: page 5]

Six Layer Detector Adapter Backplane B3

Alt. Name (FPGA) | Alt. Name (RP2040)

DETB_RUN DETB_RESERVED DETB_STATUS_SELECT DETB_END_CYC DETB_TRIGGER DETB_SELECT UART_FPGA_TO_DETB UART_DETB_TO_FPGA | GPIO06 GPIO05 GPIO04 GPIO03 GPIO02 GPIO01 GPIO00

7/9/2026 8:22 AM C:\Users\Bernhard\Proton Drive\Bernhard.Zimmermann\My files\Eagle\Projects\U01\NN2022\Backplane\SourceBackplane\CombinedBackplane01.sch (Sheet: 5/5)

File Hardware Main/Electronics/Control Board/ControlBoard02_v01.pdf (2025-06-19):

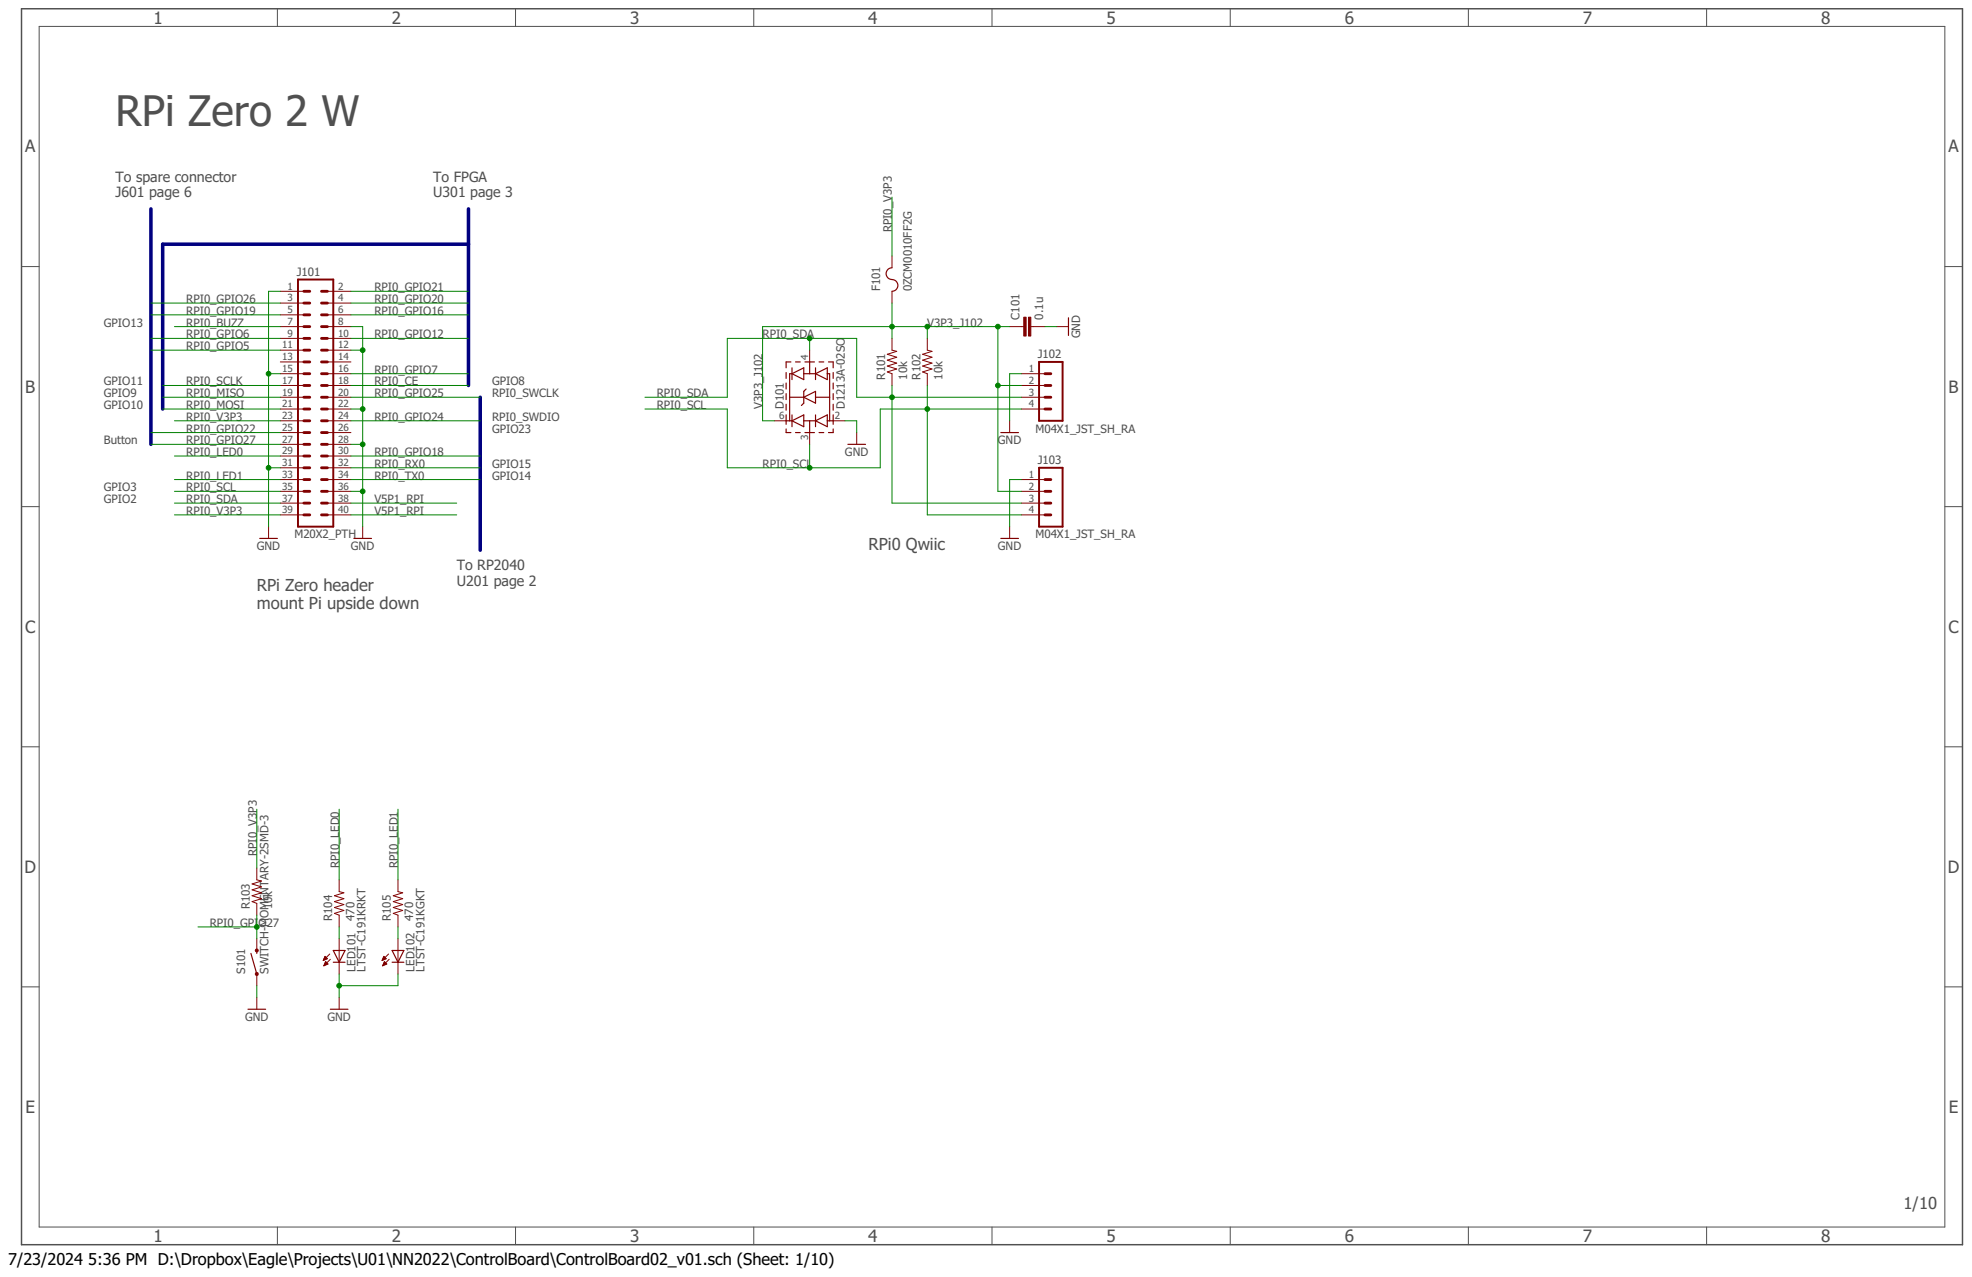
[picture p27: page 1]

RPi Zero header
mount Pi upside down

7/23/2024 5:36 PM D:\Dropbox\Eagle\Projects\U01\NN2022\ControlBoard\ControlBoard02_v01.sch (Sheet: 1/10)

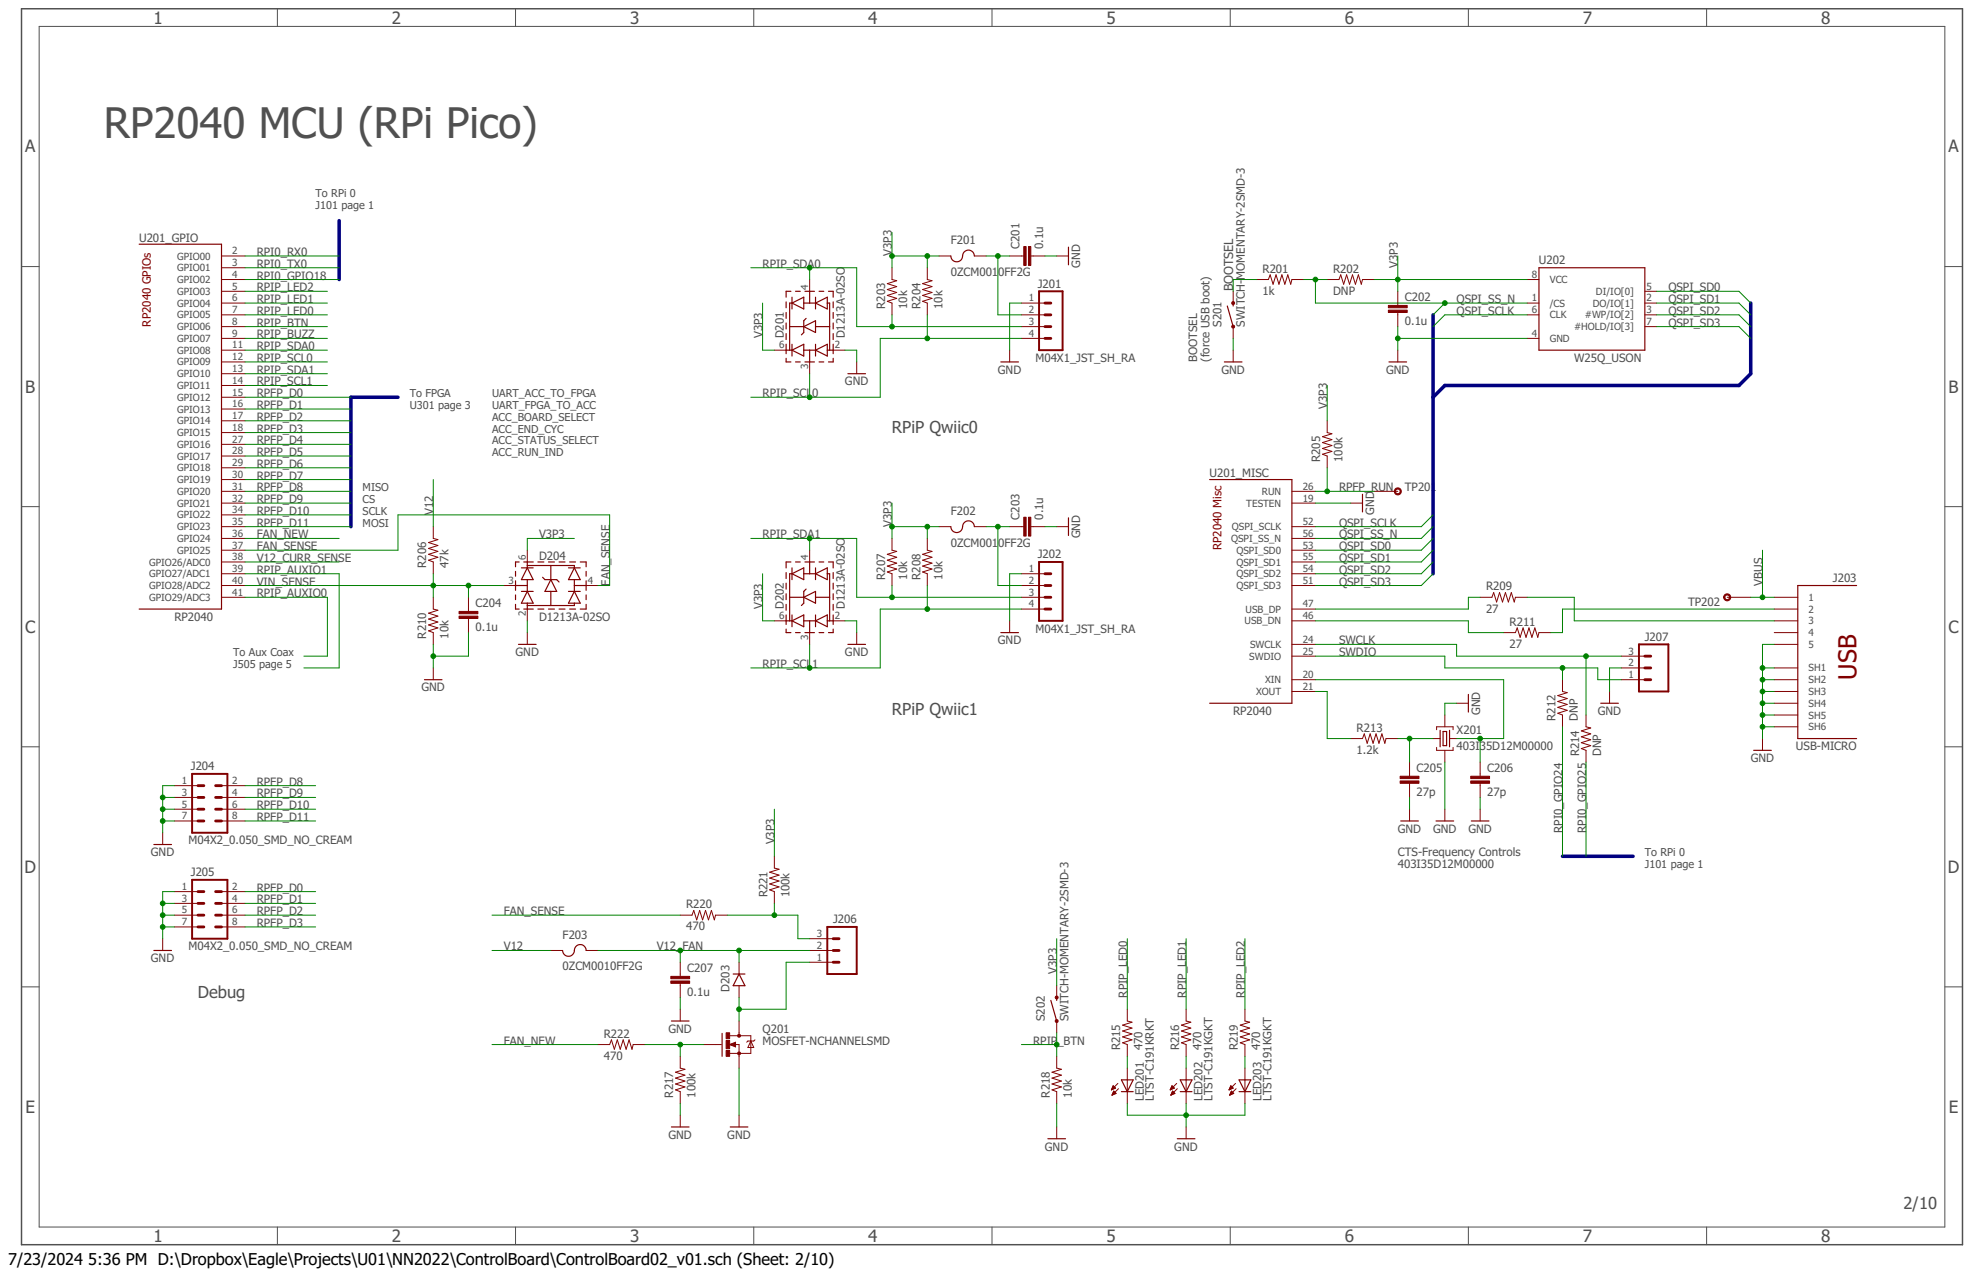
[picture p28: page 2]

7/23/2024 5:36 PM D:\Dropbox\Eagle\Projects\U01\NN2022\ControlBoard\ControlBoard02_v01.sch (Sheet: 2/10)

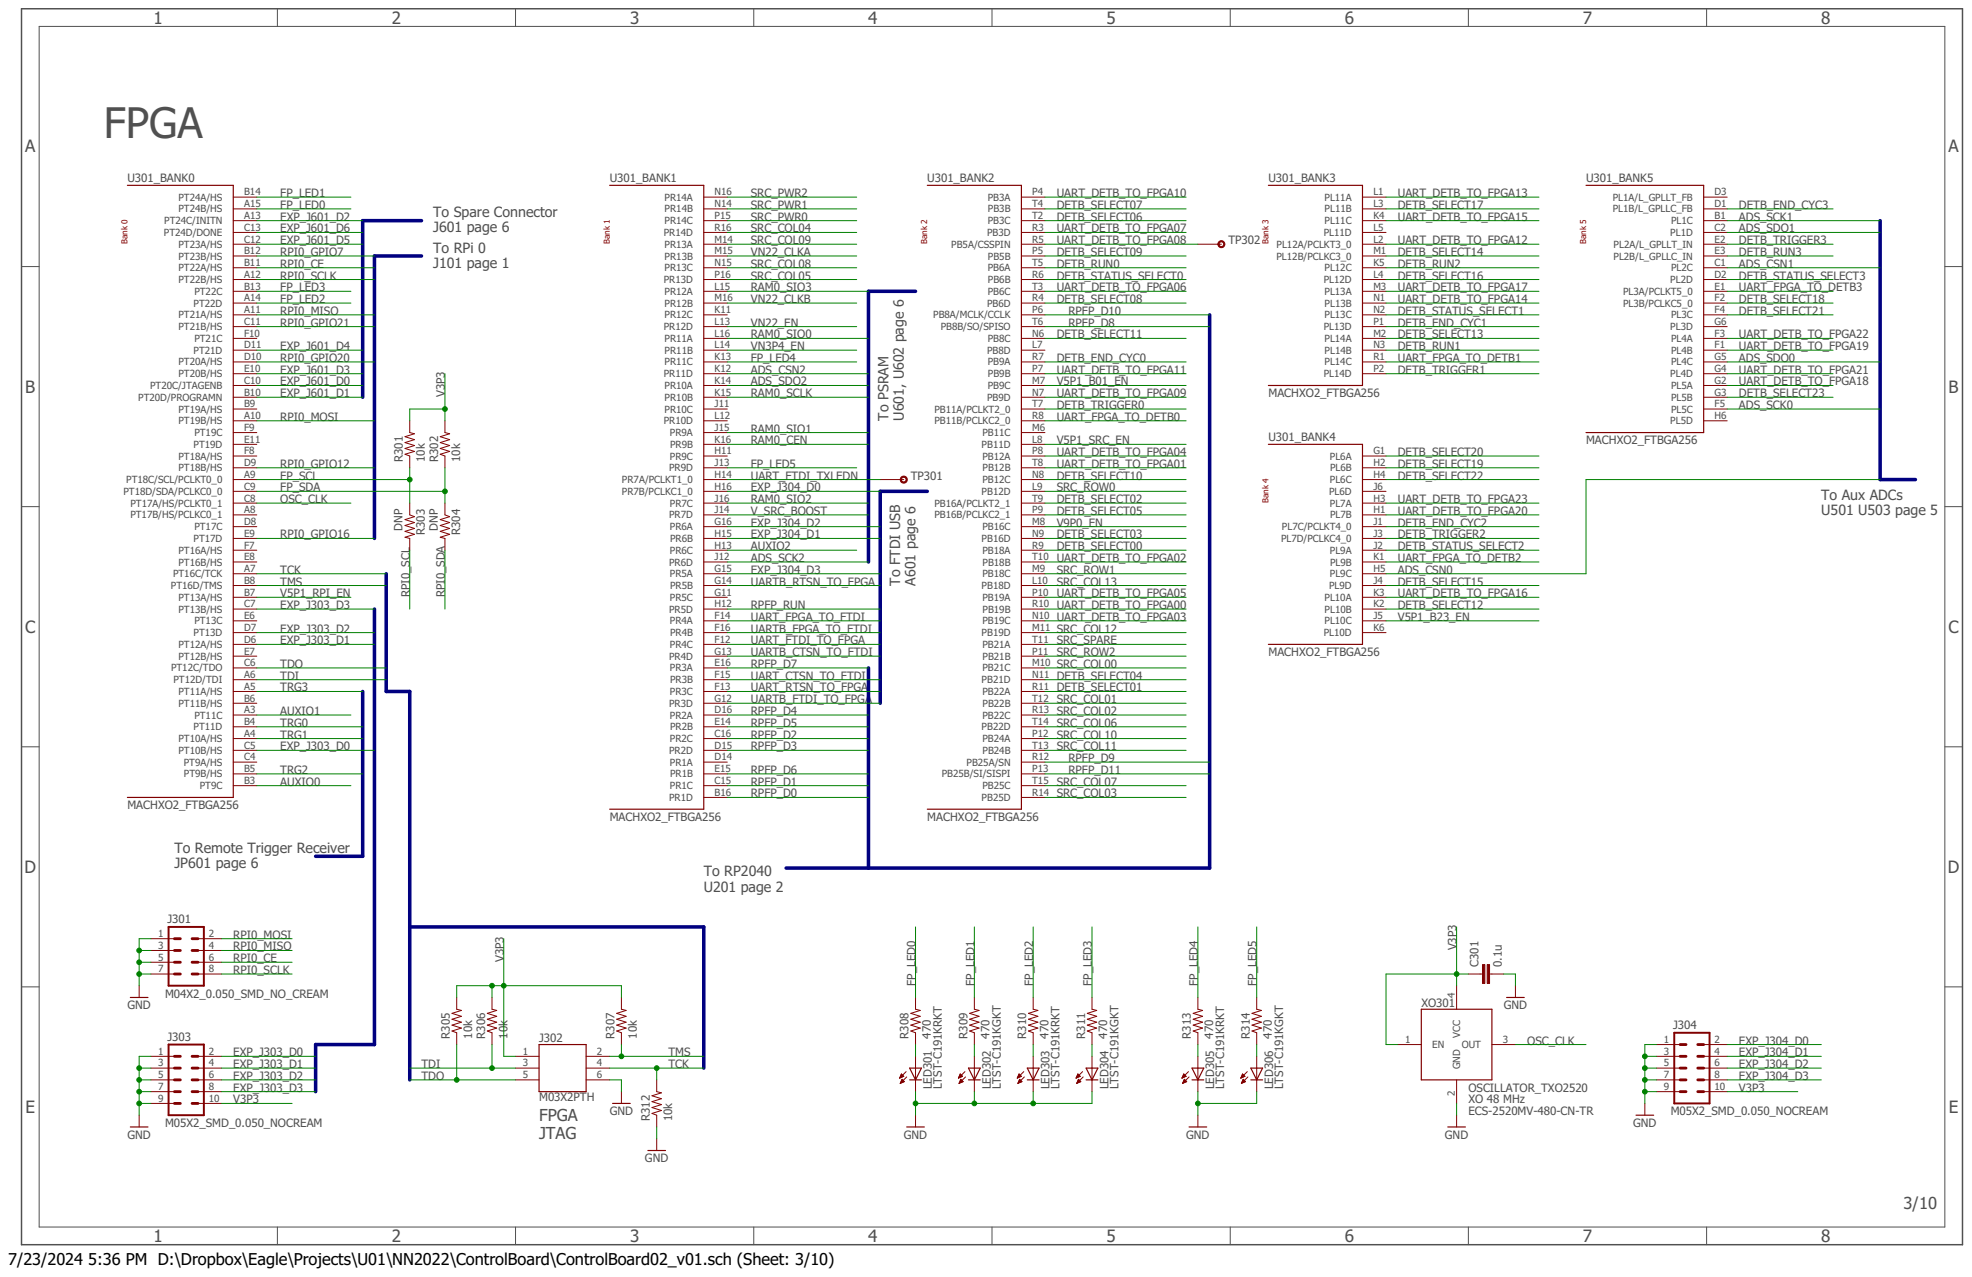
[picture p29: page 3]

To Remote Trigger Receiver
JP601 page 6

OSCILLATOR_TXO2520
XO 48 MHz ECS-2520MV-480-CN-TR

7/23/2024 5:36 PM D:\Dropbox\Eagle\Projects\U01\NN2022\ControlBoard\ControlBoard02_v01.sch (Sheet: 3/10)

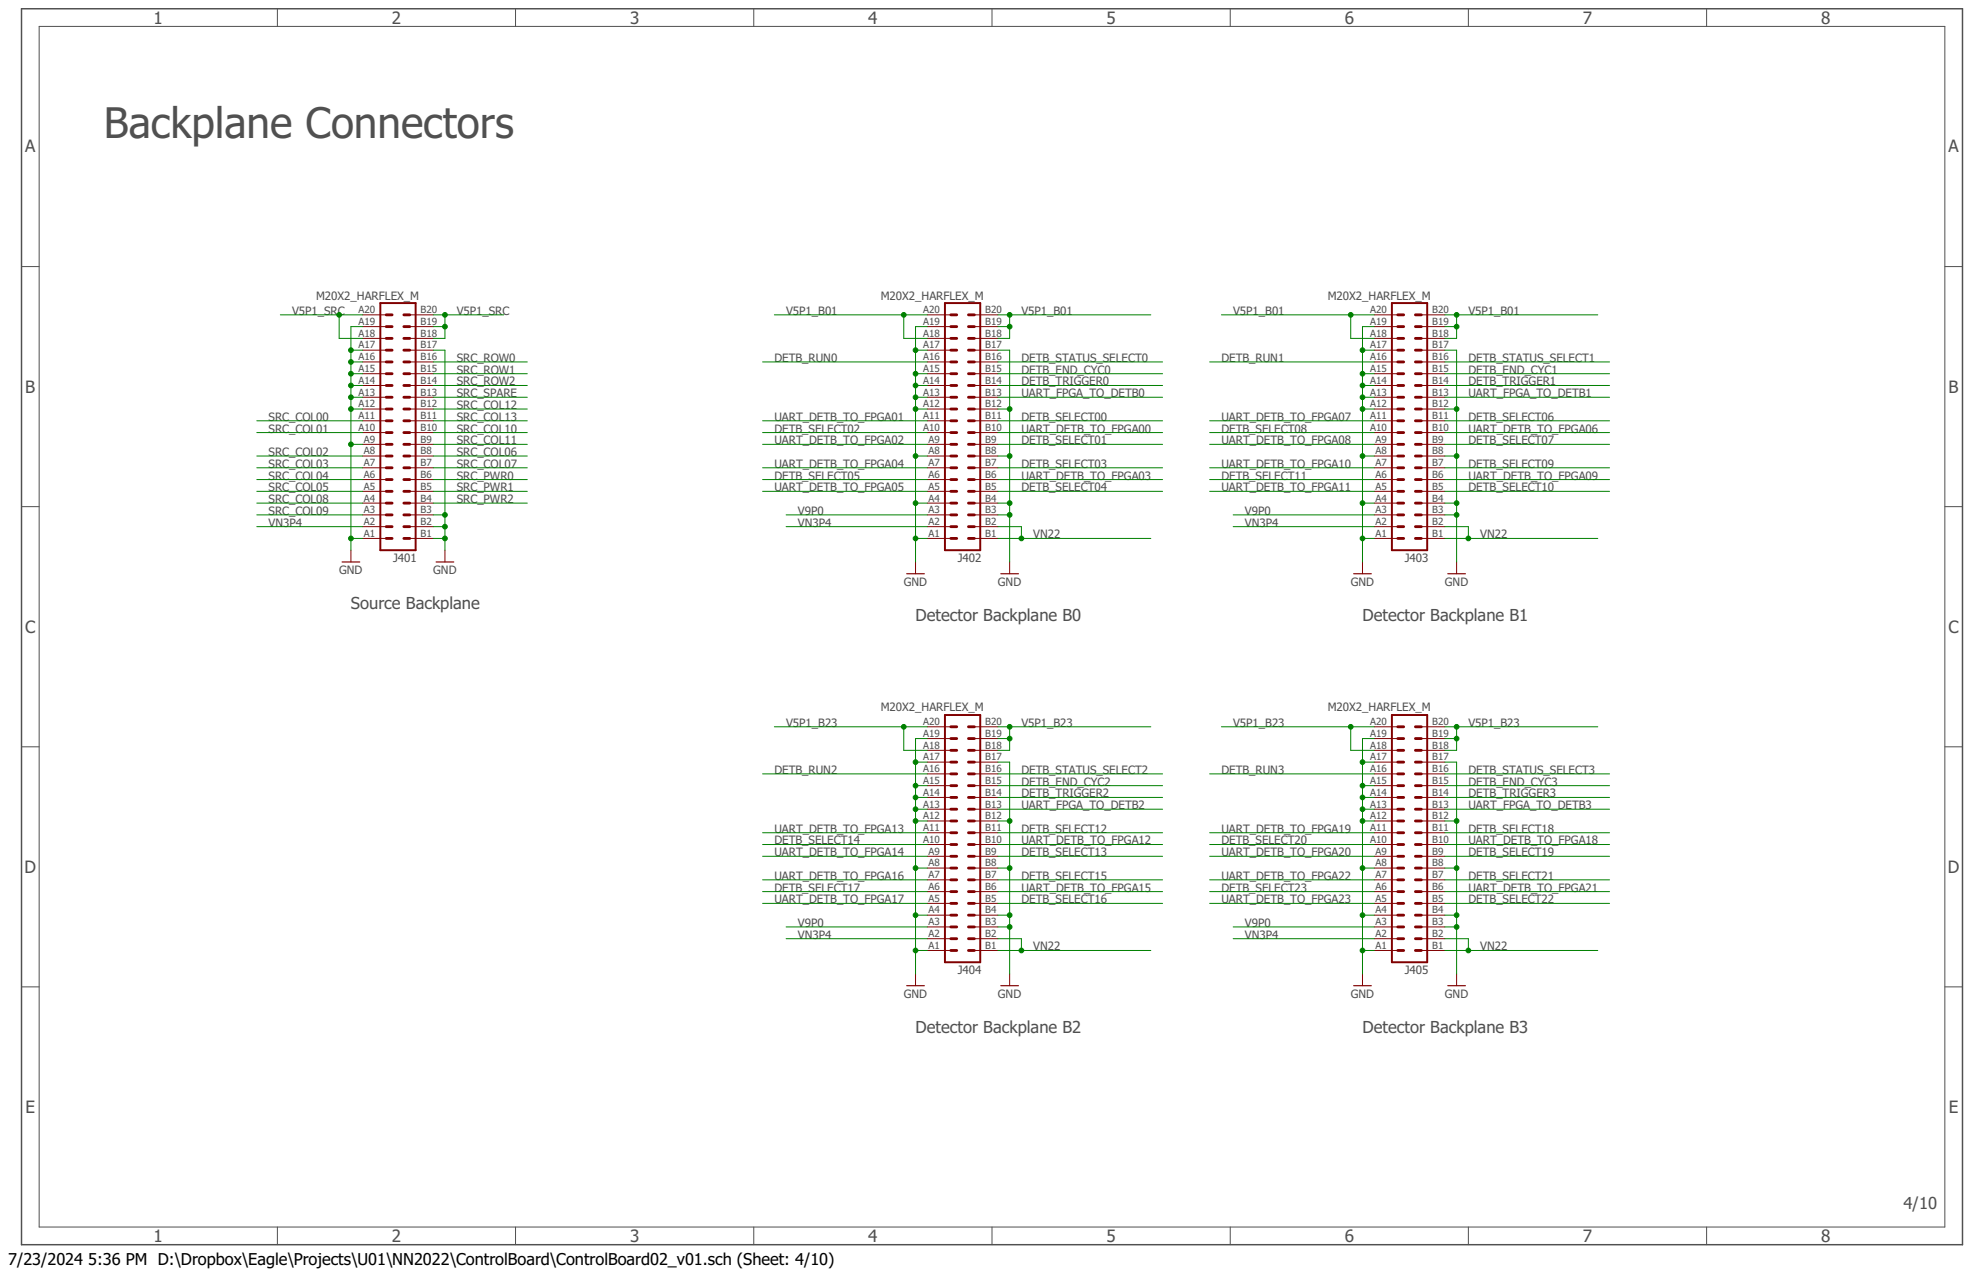
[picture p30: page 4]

7/23/2024 5:36 PM D:\Dropbox\Eagle\Projects\U01\NN2022\ControlBoard\ControlBoard02_v01.sch (Sheet: 4/10)

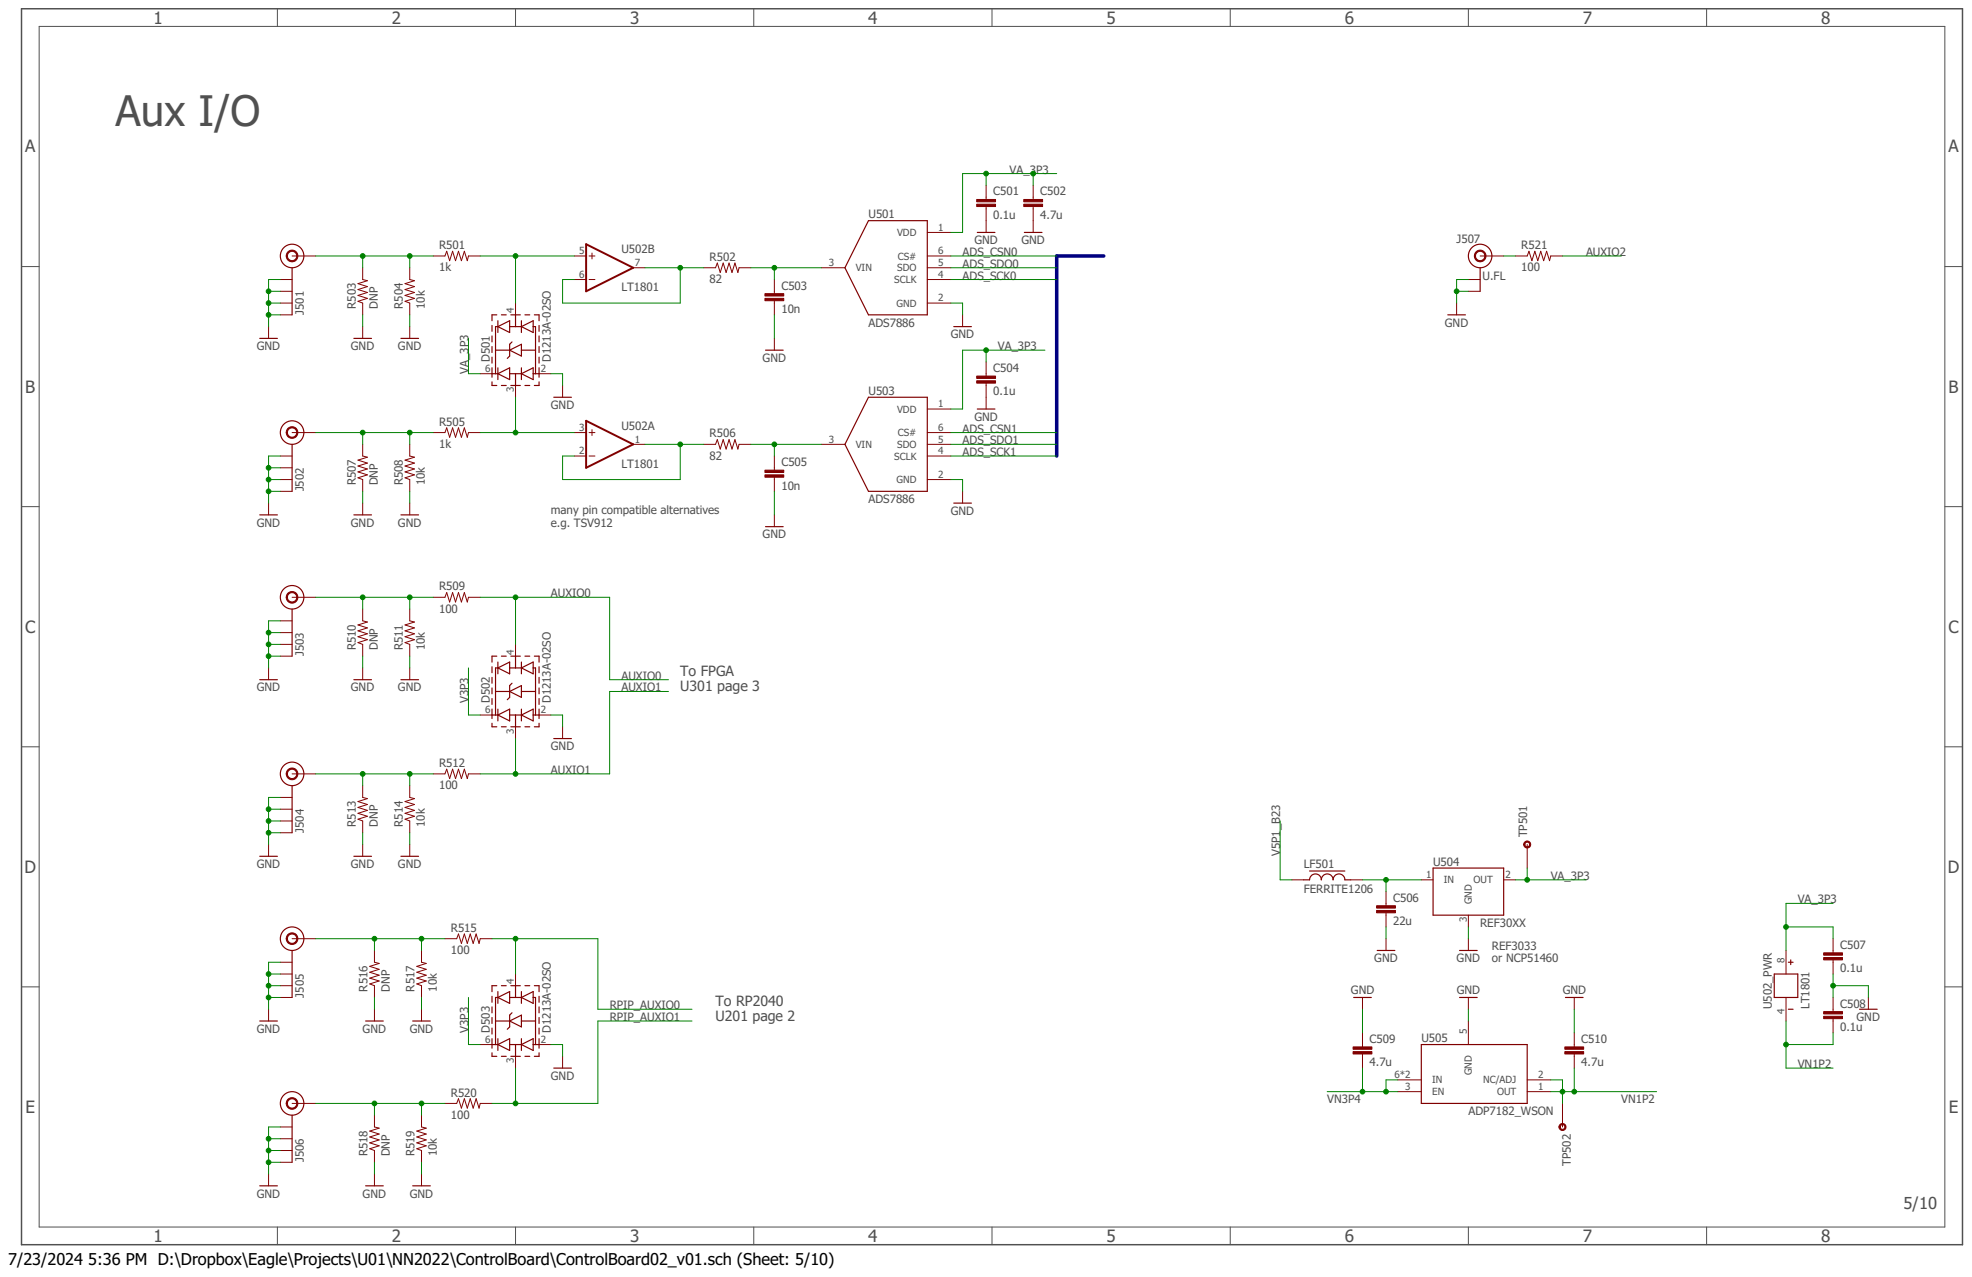
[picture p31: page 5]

many pin compatible alternatives e.g. TSV912

7/23/2024 5:36 PM D:\Dropbox\Eagle\Projects\U01\NN2022\ControlBoard\ControlBoard02_v01.sch (Sheet: 5/10)

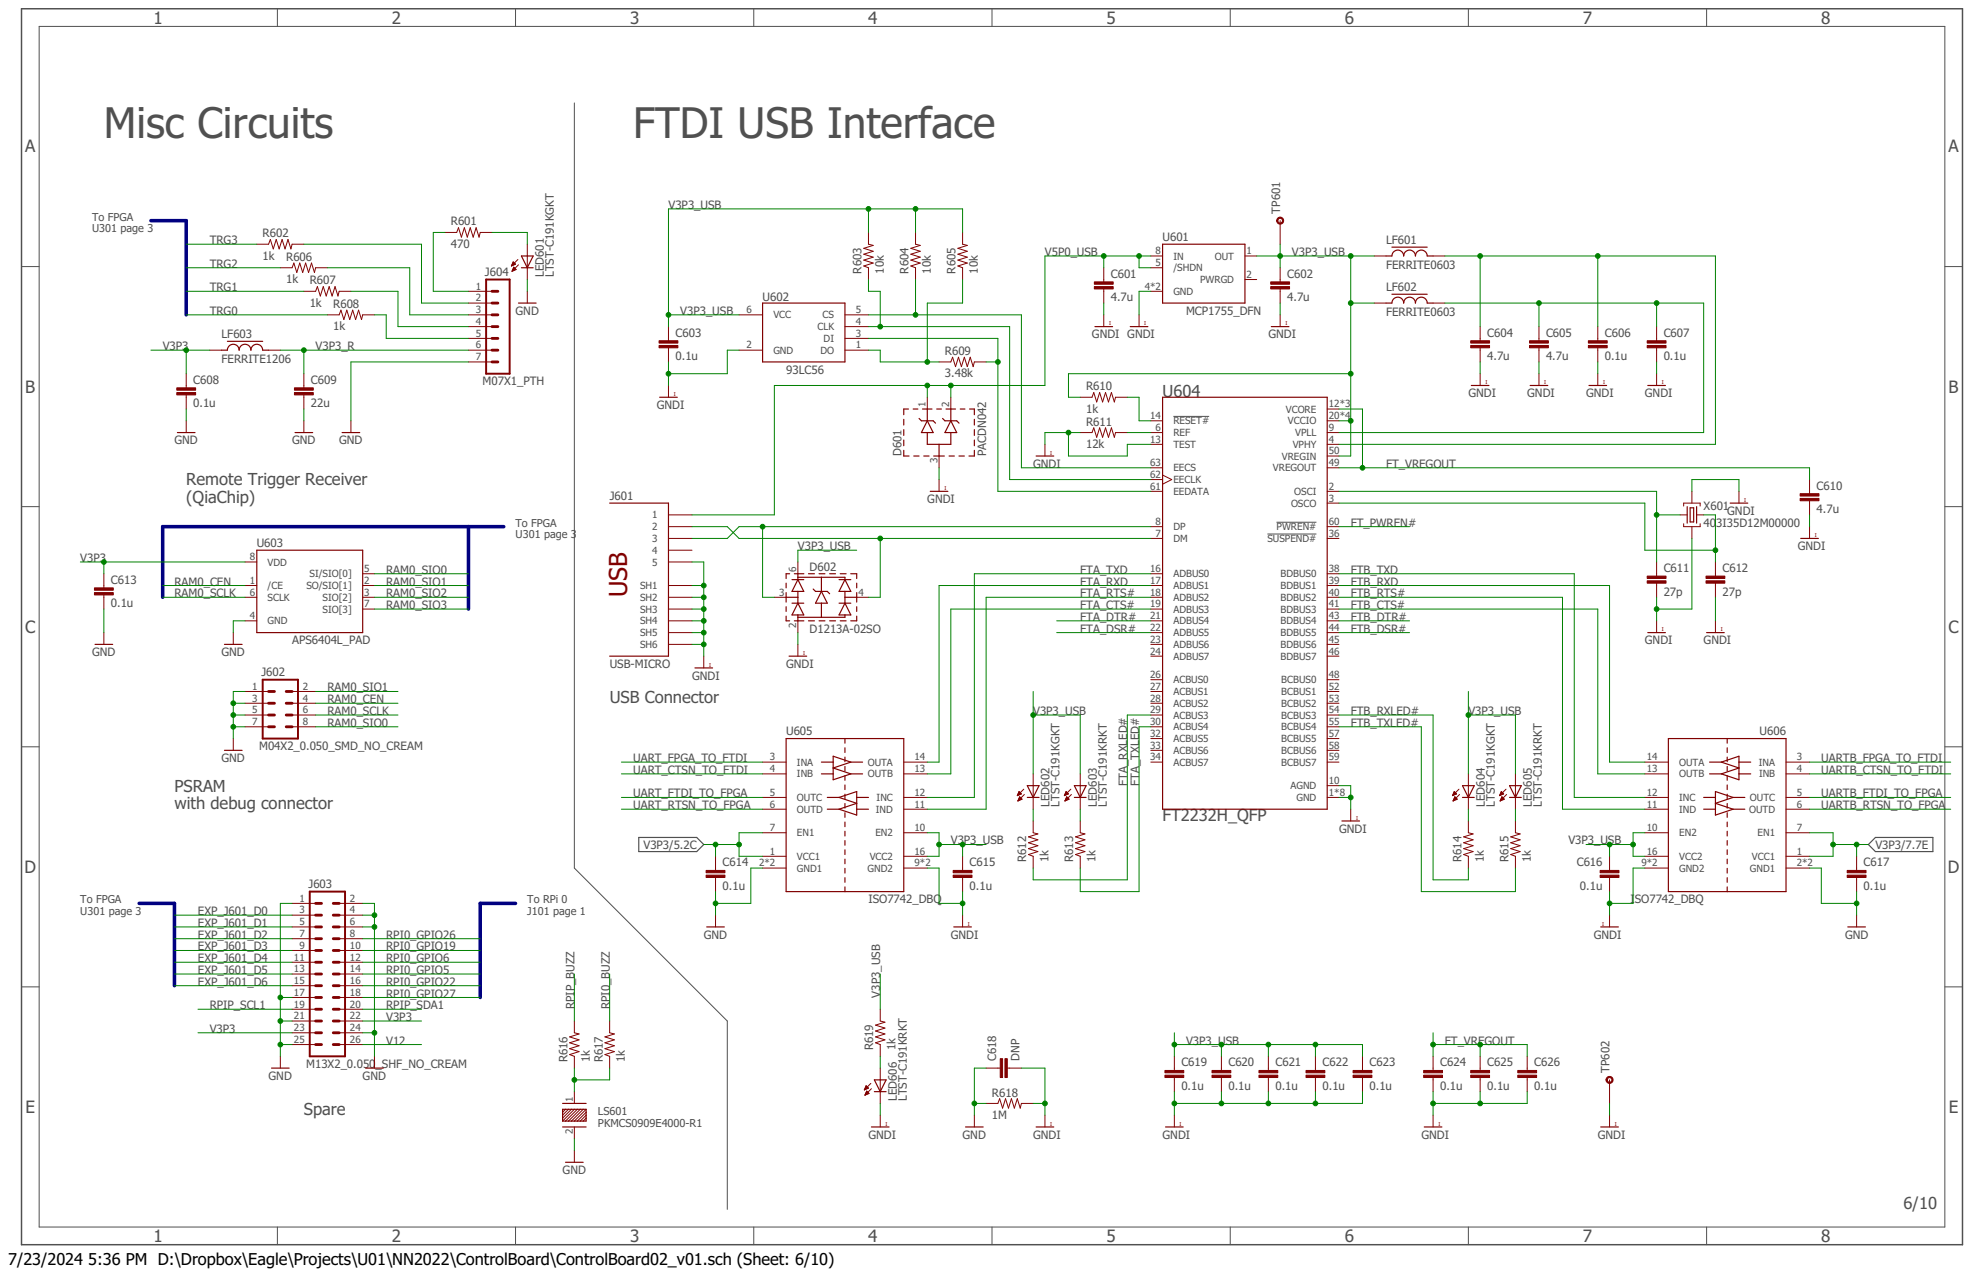
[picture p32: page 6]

7/23/2024 5:36 PM D:\Dropbox\Eagle\Projects\U01\NN2022\ControlBoard\ControlBoard02_v01.sch (Sheet: 6/10)

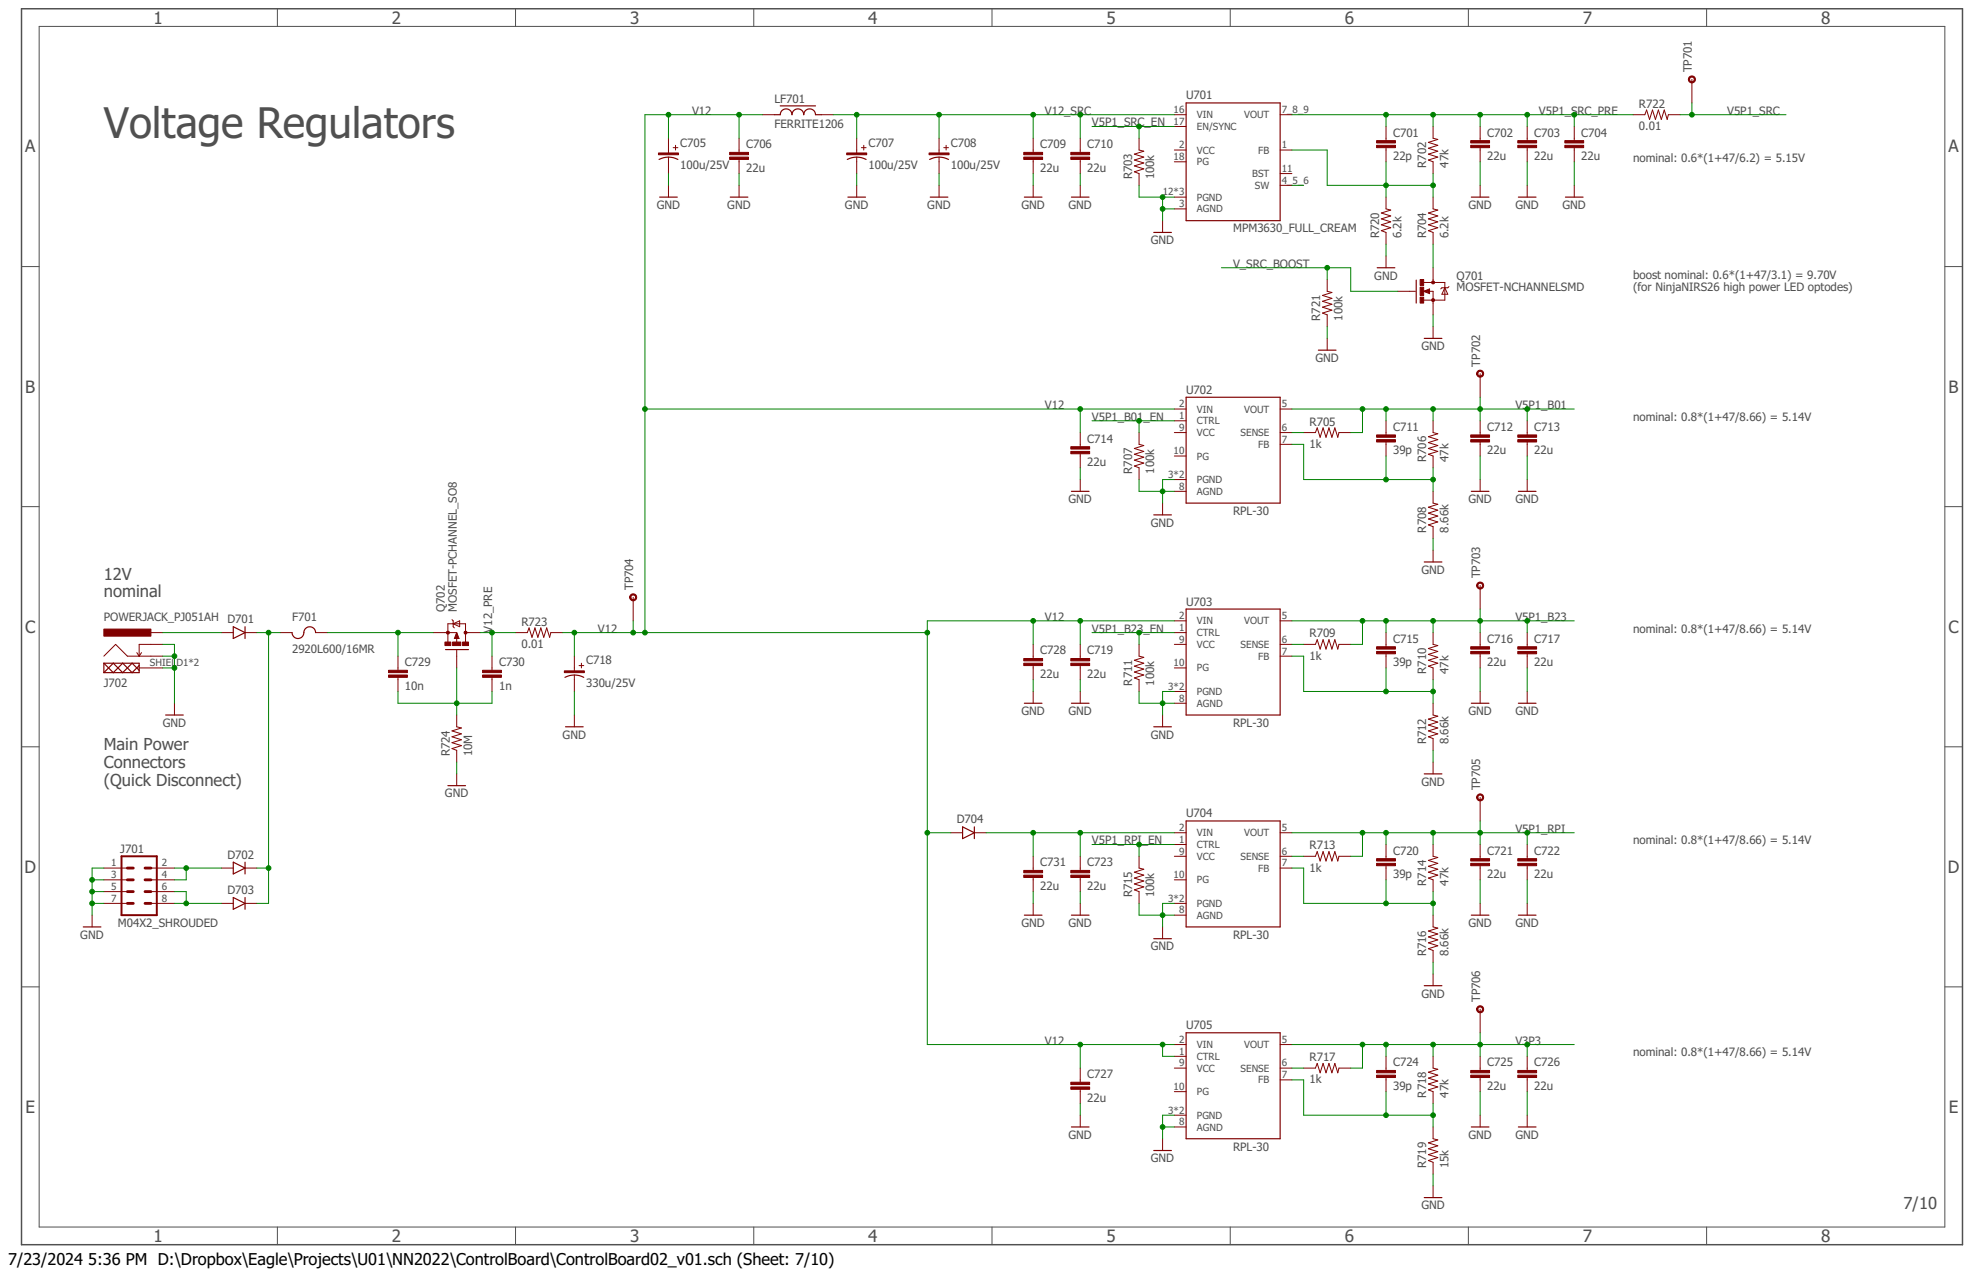
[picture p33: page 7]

boost nominal: 0.6*(1+47/3.1) = 9.70V
(for NinjaNIRS26 high power LED optodes)

7/23/2024 5:36 PM D:\Dropbox\Eagle\Projects\U01\NN2022\ControlBoard\ControlBoard02_v01.sch (Sheet: 7/10)


F4
VINREG D3 INTVCC G3 | J6 TEMP-J7 EXTVCC F3

7/23/2024 5:36 PM D:\Dropbox\Eagle\Projects\U01\NN2022\ControlBoard\ControlBoard02_v01.sch (Sheet: 8/10)


48 ADC_VDD | TP902 DVDD

43 VREG_VOUT 45 VREG_VIN

44 GND PAD GND

7/23/2024 5:36 PM D:\Dropbox\Eagle\Projects\U01\NN2022\ControlBoard\ControlBoard02_v01.sch (Sheet: 9/10)


Source Backplane Current Monitor

System Total Current Monitor

7/23/2024 5:36 PM D:\Dropbox\Eagle\Projects\U01\NN2022\ControlBoard\ControlBoard02_v01.sch (Sheet: 10/10)

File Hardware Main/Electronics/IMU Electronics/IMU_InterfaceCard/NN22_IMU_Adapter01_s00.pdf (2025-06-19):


RX: from IMU Adapter to IMU Board
TX: from IMU Board to IMU Adapter
(IMU Board centric labeling)


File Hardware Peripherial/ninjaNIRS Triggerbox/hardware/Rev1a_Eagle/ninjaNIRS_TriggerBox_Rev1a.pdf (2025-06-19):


TE_CON_BNC_5227161-9 TE_CON_BNC_5227161-9 TE_CON_BNC_5227161-9 TE_CON_BNC_5227161-9 MINI-USB-UX60A-MB-5ST 10uF 100 GND GNDCONN RCPT 7POS 0.1" GOLD PCB R/A GND E-SWITCH-800BWSP9SM6RE E-SWITCH-800BWSP9SM6RE E-SWITCH-800BWSP9SM6RE E-SWITCH-800BWSP9SM6RE LTST-C191KGKT 1k Antenna 10k 10k 10k 10k 10k 10k 10k 10k SN74HCS08-Q1 SN74HCS08-Q1 SN74HCS08-Q1 SN74HCS08-Q1 GND GND +5V 100nF GND GND GND GND GND GND +5V +5V +5V +5V +5V +5V +5V +5V 100nF+5V 10uF GND 39 47n 47n 47n 47n 39 39 39 PNP MMB+T3906 5V 1k Kingbright APA1606QBC/D 100 GND PNP MMBT3906 +5V 1k Kingbright APA1606QBC/D 100 GND PNP MMBT3906 +5V 1k Kingbright APA1606QBC/D 100 GND PNP MMBT3906 +5V 1k Kingbright APA1606QBC/D 100 GND 10uF 100nF GND +5V PNP MMBT3906 GND 1k1k 1k1k PNP MMBT3906 PNP MMBT3906 PNP MMBT3906 GND GNDGND SHIELD P$3 SIG P$4 N/C2 P$2 N/C1 XP$1 2 SHIELD P$3 SIG P$4 N/C2 P$2 N/C1 XP$1 3 SHIELD P$3 SIG P$4 N/C2 P$2 N/C1 XP$1 4 SHIELD P$3 SIG P$4 N/C2 P$2 N/C1 XP$1 5 X1 12345 C1 R1 JP11234567 P$1 P$1 P$2 P$2 S2 P$1 P$1 P$2 P$2 S3 P$1 P$1 P$2 P$2 S5 P$1 P$1 P$2 P$2 S4 LED1 R2 JP2 1 R3 R4 R5 R6 R7R8 R9R10 1 IC1A 2 3 4 IC1B 5 6 9 IC1C 10 8 12 IC1D 13 11 C2 IC1PGND VCC 7 14 C4 C3 R11 C5C6 C7C8 R12 R13 R14 T1R15 LED2 R16 T2R17 LED3 R18 T3R19 LED4 R20 T4R21 LED5 R22 C9 C10 T5R23R24 R25R26 T6 T8 T7 K1 K1 K2 K2 K4 K4 K3 K3 ninjaNIRS_TriggerBox_Rev1a 11/23/2020 12:10 PM Sheet: 1/1 ABCD 1 2 3 4 5 6 ABCD 1 2 3 4 5 6

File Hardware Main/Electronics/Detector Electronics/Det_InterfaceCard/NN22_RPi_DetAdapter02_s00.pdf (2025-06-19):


VOCM /DISABLE -VS

3/20/2024 3:26 PM D:\Dropbox\Eagle\Projects\U01\NN2022\DetAdapter\v02\NN22_RPi_DetAdapter02_s00.sch (Sheet: 1/6)


VOCM /DISABLE -VS

3/20/2024 3:26 PM D:\Dropbox\Eagle\Projects\U01\NN2022\DetAdapter\v02\NN22_RPi_DetAdapter02_s00.sch (Sheet: 2/6)


VOCM /DISABLE -VS

3/20/2024 3:26 PM D:\Dropbox\Eagle\Projects\U01\NN2022\DetAdapter\v02\NN22_RPi_DetAdapter02_s00.sch (Sheet: 3/6)


VOCM /DISABLE -VS

3/20/2024 3:26 PM D:\Dropbox\Eagle\Projects\U01\NN2022\DetAdapter\v02\NN22_RPi_DetAdapter02_s00.sch (Sheet: 4/6)


3/20/2024 3:26 PM D:\Dropbox\Eagle\Projects\U01\NN2022\DetAdapter\v02\NN22_RPi_DetAdapter02_s00.sch (Sheet: 5/6)


48 ADC_VDD
43 VREG_VOUT 45 VREG_VIN | TP21

use 5V fixed output version
ADP7142ACPZN5.0-R7

3/20/2024 3:26 PM D:\Dropbox\Eagle\Projects\U01\NN2022\DetAdapter\v02\NN22_RPi_DetAdapter02_s00.sch (Sheet: 6/6)





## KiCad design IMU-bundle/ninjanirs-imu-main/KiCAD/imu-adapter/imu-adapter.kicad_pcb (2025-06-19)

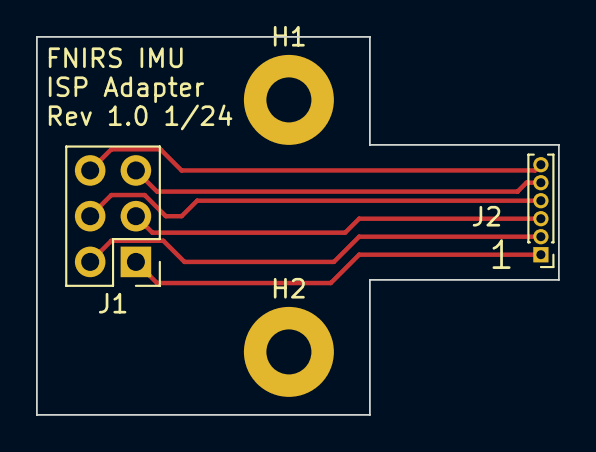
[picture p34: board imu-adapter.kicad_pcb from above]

Board: 2 copper layers, 29.0 x 21.0 mm, 4 parts (0 on the bottom side), 6 nets.

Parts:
H1, H2: MountingHole; MountingHole_2.5mm_Pad
J1: 2x3_0.1in; PinHeader_2x03_P2.54mm_Vertical
J2: 1mm_SIP; PinHeader_1x06_P1.00mm_Vertical

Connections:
unnamed: J1.6 (GND), J2.6 (GND)
unnamed: J1.1 (MISO), J2.1 (MISO)
unnamed: J1.4 (MOSI), J2.4 (MOSI)
unnamed: J1.3 (SCK), J2.3 (SCK)
unnamed: J1.2 (VCC), J2.2 (VCC)
unnamed: J1.5 (~RST), J2.5 (~RST)

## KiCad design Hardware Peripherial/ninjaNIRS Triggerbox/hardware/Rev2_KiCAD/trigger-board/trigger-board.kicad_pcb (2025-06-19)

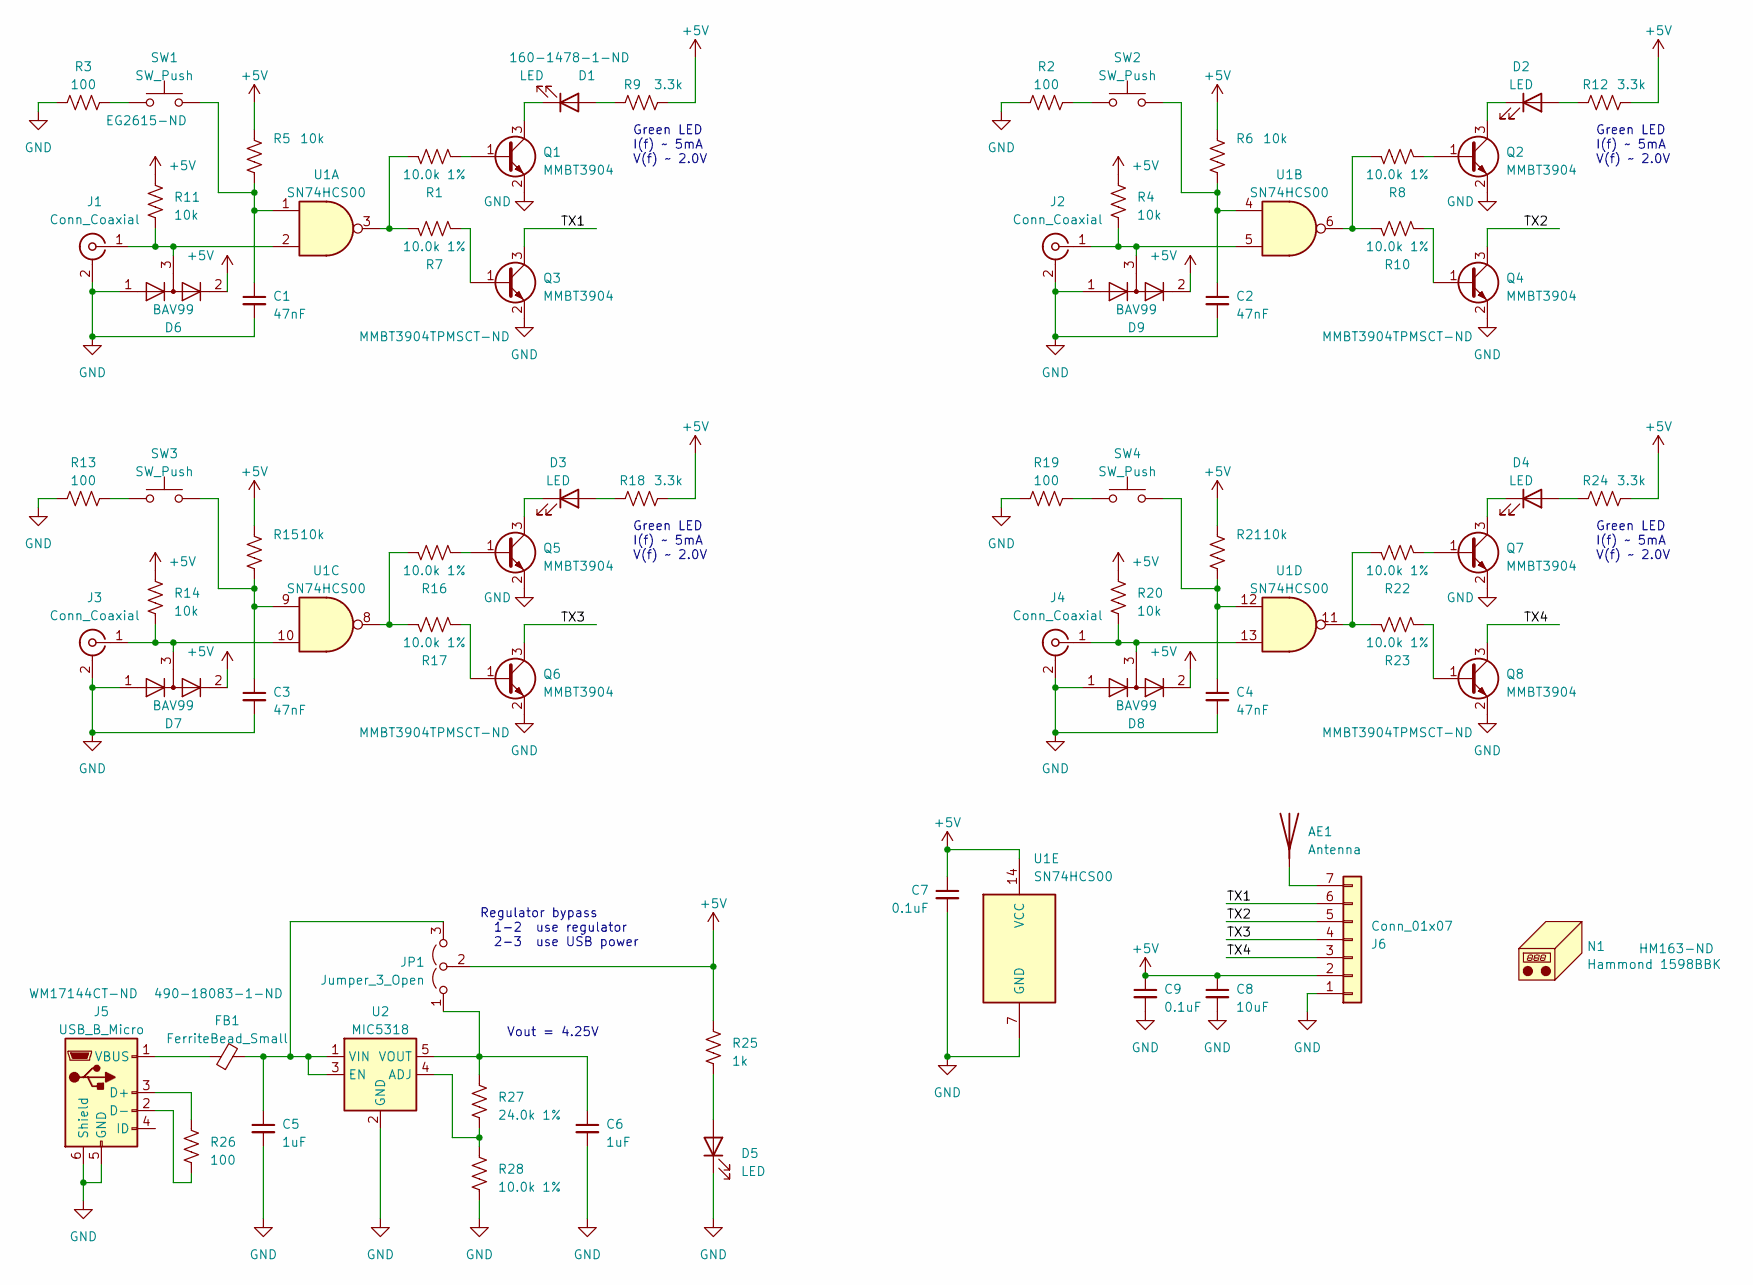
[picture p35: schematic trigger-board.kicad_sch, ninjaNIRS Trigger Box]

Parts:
AE1: Antenna; PinHeader_1x01_P2.54mm_Vertical; Manufacturers P/N -DNP-
C1, C2, C3, C4: 47nF; C_0805_2012Metric_Pad1.18x1.45mm_HandSolder; Manufacturers P/N CL21B473KCCWPNC
C5, C6: 1uF; C_0805_2012Metric_Pad1.18x1.45mm_HandSolder; Manufacturers P/N CL21B105KPFNNNE
C7, C9: 0.1uF; C_0805_2012Metric_Pad1.18x1.45mm_HandSolder; Manufacturers P/N 08053C104KAT2A
C8: 10uF; C_0805_2012Metric_Pad1.18x1.45mm_HandSolder; Manufacturers P/N CL21A106KOQNNNE
D1, D2, D3, D4: LED; LED_0603_marked; Manufacturers P/N 160-1478-1-ND
D5: LED; LED_0603_marked; Manufacturers P/N LTST-S270EKT
D6, D7, D8, D9: BAV99; SOT-23; Manufacturers P/N BAV99,215
FB1: FerriteBead_Small; L_1210_3225Metric_Pad1.42x2.65mm_HandSolder; Manufacturers P/N BLM31KN102BH1L
J1, J2, J3, J4: Conn_Coaxial; BNC_Amphenol_B6252HB-NPP3G-50_Horizontal; Manufacturers P/N RF1-01K-D-00-50-BK-HDW
J5: USB_B_Micro; USB_Micro-AB_Molex_47590-0001; Manufacturers P/N 0475900001
J6: Conn_01x07; PinSocket_1x07_P2.54mm_Horizontal; Manufacturers P/N SSW-107-02-G-S-RA
JP1: Jumper_3_Open; PinHeader_1x03_P2.54mm_Vertical; Manufacturers P/N 61300311121
N1: Hammond 1598BBK; Hammond_1598B; Manufacturers P/N -DNP-
Q1, Q2, Q3, Q4, Q5, Q6, Q7, Q8: MMBT3904; SOT-23; Manufacturers P/N MMBT3904-TP
R1, R7, R8, R10, R16, R17, R22, R23, R28: 10.0k 1%; R_0805_2012Metric_Pad1.20x1.40mm_HandSolder; Manufacturers P/N RNCP0805FTD10K0
R2, R3, R13, R19, R26: 100; R_0805_2012Metric_Pad1.20x1.40mm_HandSolder; Manufacturers P/N RC0805FR-07100RL
R4, R5, R6, R11, R14, R15, R20, R21: 10k; R_0805_2012Metric_Pad1.20x1.40mm_HandSolder; Manufacturers P/N RNCP0805FTD1K00
R9, R12, R18, R24: 3.3k; R_0805_2012Metric_Pad1.20x1.40mm_HandSolder; Manufacturers P/N RC0805FR-073K3L
R25: 1k; R_0805_2012Metric_Pad1.20x1.40mm_HandSolder; Manufacturers P/N RNCP0805FTD1K00
R27: 24.0k 1%; R_0805_2012Metric_Pad1.20x1.40mm_HandSolder; Manufacturers P/N RMCF0805FT24K0
SW1, SW2, SW3, SW4: SW_Push; 800SP9B6M6RE; Manufacturers P/N 800SP9B6M6RE
U1: SN74HCS00; SOIC-14_3.9x8.7mm_P1.27mm; Manufacturers P/N SN74HCS00DR
U2: MIC5318; SOT-23-5_HandSoldering; Manufacturers P/N MIC5318YD5-TR

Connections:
+5V: C7.1, C8.1, C9.1, D6.2 (A), D7.2 (A), D8.2 (A), D9.2 (A), J6.2, JP1.2 (C), R4.2, R5.2, R6.2, R9.1, R11.2, R12.1, R14.2, R15.2, R18.1, R20.2, R21.2, R24.1, R25.1, U1.14 (VCC)
/TX1: J6.6, Q3.3 (C)
/TX2: J6.5, Q4.3 (C)
/TX3: J6.4, Q6.3 (C)
/TX4: J6.3, Q8.3 (C)
GND: C1.2, C2.2, C3.2, C4.2, C5.2, C6.2, C7.2, C8.2, C9.2, D5.1 (K), D6.1 (K), D7.1 (K), D8.1 (K), D9.1 (K), J1.2 (Ext), J2.2 (Ext), J3.2 (Ext), J4.2 (Ext), J5.5 (GND), J5.6 (Shield), J6.1, Q1.2 (E), Q2.2 (E), Q3.2 (E), Q4.2 (E), Q5.2 (E), Q6.2 (E), Q7.2 (E), Q8.2 (E), R2.2, R3.2, R13.2, R19.2, R28.1, U1.7 (GND), U2.2 (GND)
unnamed: AE1.1 (A), J6.7
unnamed: C1.1, R5.1, SW1.2, U1.1
unnamed: C2.1, R6.1, SW2.2, U1.4
unnamed: C3.1, R15.1, SW3.2, U1.9
unnamed: C4.1, R21.1, SW4.2, U1.12
unnamed: D1.2 (A), R9.2
unnamed: D1.1 (K), Q1.3 (C)
unnamed: D2.2 (A), R12.2
unnamed: D2.1 (K), Q2.3 (C)
unnamed: D3.2 (A), R18.2
unnamed: D3.1 (K), Q5.3 (C)
unnamed: D4.2 (A), R24.2
unnamed: D4.1 (K), Q7.3 (C)
unnamed: D5.2 (A), R25.2
unnamed: D6.3 (K), J1.1 (In), R11.1, U1.2
unnamed: D9.3 (K), J2.1 (In), R4.1, U1.5
unnamed: D7.3 (K), J3.1 (In), R14.1, U1.10
unnamed: D8.3 (K), J4.1 (In), R20.1, U1.13
unnamed: J5.3 (D+), R26.2
unnamed: J5.2 (D-), R26.1
unnamed: FB1.1, J5.1 (VBUS)
unnamed: C6.1, JP1.1 (A), R27.2, U2.5 (VOUT)
unnamed: C5.1, FB1.2, JP1.3 (B), U2.1 (VIN), U2.3 (EN)
unnamed: Q1.1 (B), R1.2
unnamed: Q2.1 (B), R8.2
unnamed: Q3.1 (B), R7.2
unnamed: Q4.1 (B), R10.2
unnamed: Q5.1 (B), R16.2
unnamed: Q6.1 (B), R17.2
unnamed: Q7.1 (B), R22.2
unnamed: Q8.1 (B), R23.2
unnamed: R1.1, R7.1, U1.3
unnamed: R2.1, SW2.1
unnamed: R3.1, SW1.1
unnamed: R8.1, R10.1, U1.6
unnamed: R13.1, SW3.1
unnamed: R16.1, R17.1, U1.8
unnamed: R19.1, SW4.1
unnamed: R22.1, R23.1, U1.11
unnamed: R27.1, R28.2, U2.4 (ADJ)

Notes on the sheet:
Vout = 4.25V
Green LED I(f) ~ 5mA V(f) ~ 2.0V
Regulator bypass 1-2 use regulator 2-3 use USB power

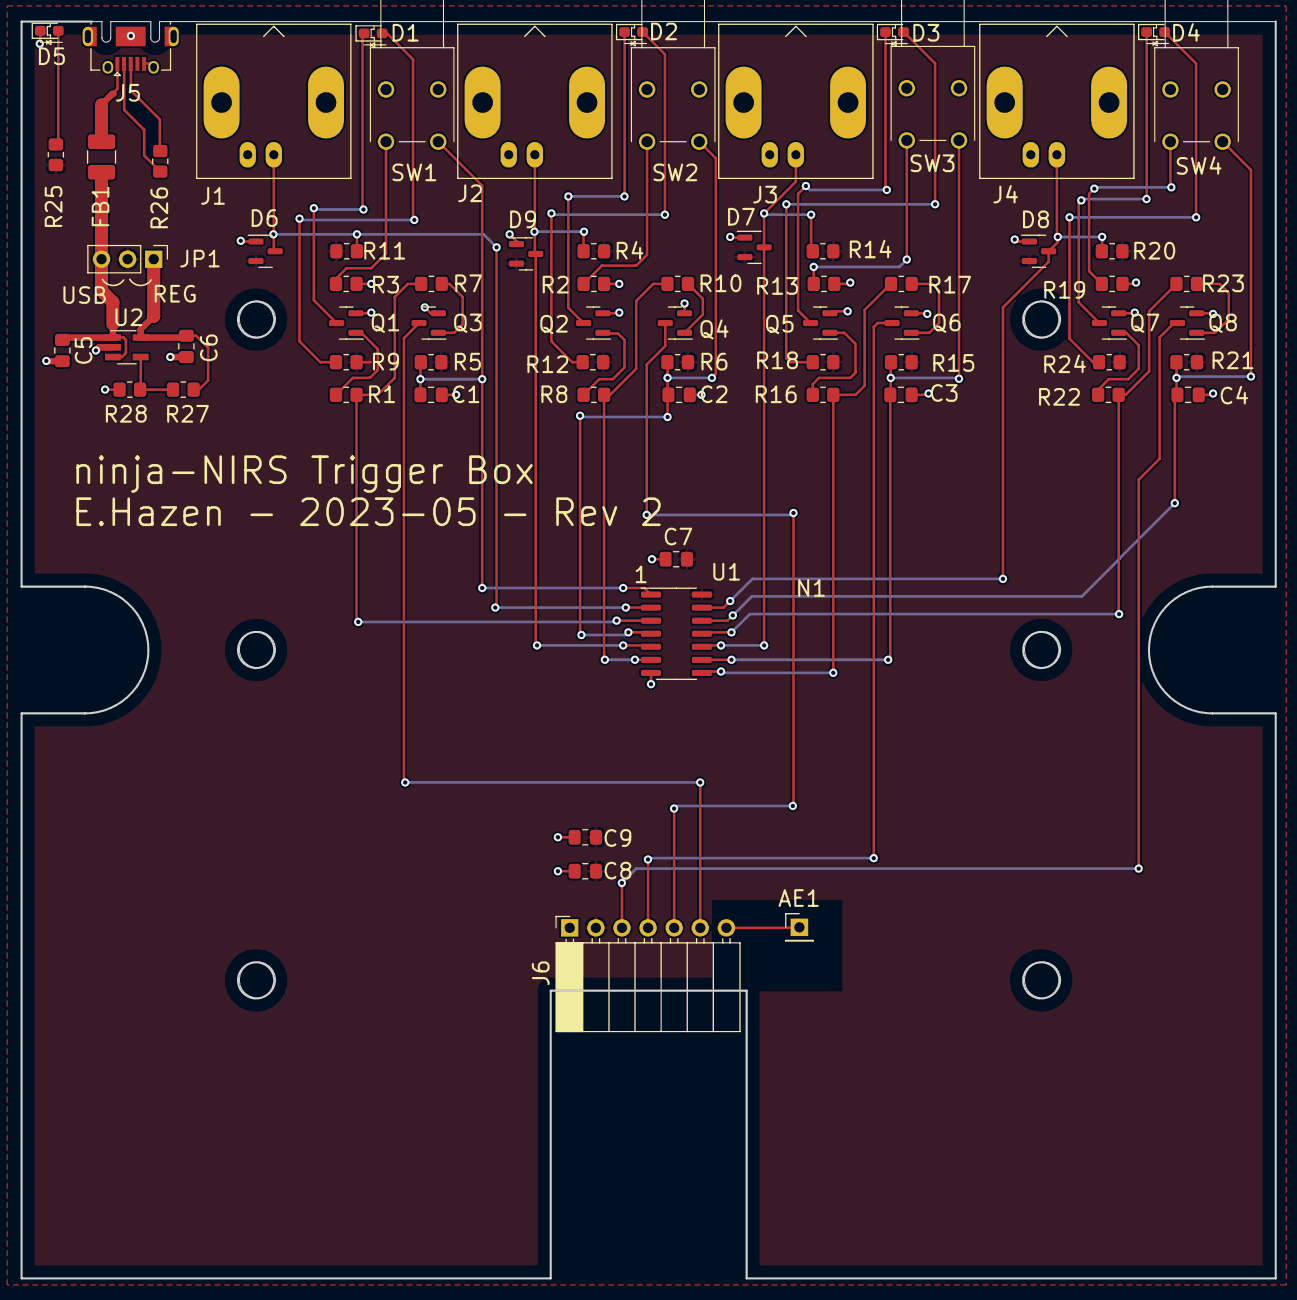
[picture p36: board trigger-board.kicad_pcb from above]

Board: 2 copper layers, 122.0 x 122.3 mm, 70 parts (0 on the bottom side), 46 nets.

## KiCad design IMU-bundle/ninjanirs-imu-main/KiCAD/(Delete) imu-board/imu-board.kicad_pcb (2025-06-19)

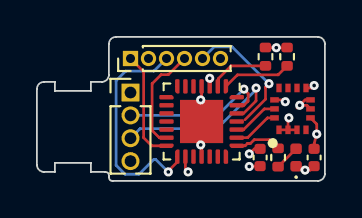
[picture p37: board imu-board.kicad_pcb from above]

Board: 4 copper layers, 16.0 x 8.0 mm, 10 parts (0 on the bottom side), 14 nets.

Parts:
C1, C2: C_Small; C_0402_1005Metric
D1: LED; LED_0402_1005Metric
J1: Conn_01x04; PinHeader_1x04_P1.27mm_Vertical
J3: AVR-ISP-6; PinHeader_1x06_P1.00mm_Vertical
JP1, JP2: JPR2; R_0402_1005Metric
R1: R_US; R_0402_1005Metric
U2: ISM330DHCX; LGA-14L
U3: ATmega168A-MM; QFN-28-1EP_4x4mm_P0.45mm_EP2.4x2.4mm

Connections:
/MISO: J3.1 (MISO), U3.14 (PB4)
/MOSI: J3.4 (MOSI), U3.13 (PB3)
/RXD: J1.3, U3.26 (PD0)
/SCK: J3.3 (SCK), U3.15 (PB5)
/SCL: U2.P13 (SCL), U3.24 (PC5)
/SDA: U2.P14 (SDA/SDI/SDO), U3.23 (PC4)
/TXD: J1.2, U3.27 (PD1)
/nRESET: J3.5 (~RST), U3.25 (~RESET/PC6)
GND: C1.2, C2.2, D1.1 (K), J1.4, J3.6 (GND), JP1.2 (B), JP2.2 (B), U2.P1 (SDO/SA0), U2.P2 (SDX), U2.P3 (SCX), U2.P6 (GND@6), U2.P7 (GND@7), U3.4 (GND), U3.18 (GND), U3.29 (GND)
unnamed: D1.2 (A), R1.2
unnamed: JP1.1 (A), U3.2 (PD4)
unnamed: JP2.1 (A), U3.1 (PD3)
unnamed: R1.1, U3.22 (PC3)
VCC: C1.1, C2.1, J1.1, J3.2 (VCC), U2.P5 (VDD_IO), U2.P8 (VDD), U2.P12 (~CS), U3.3 (VCC), U3.16 (AVCC)

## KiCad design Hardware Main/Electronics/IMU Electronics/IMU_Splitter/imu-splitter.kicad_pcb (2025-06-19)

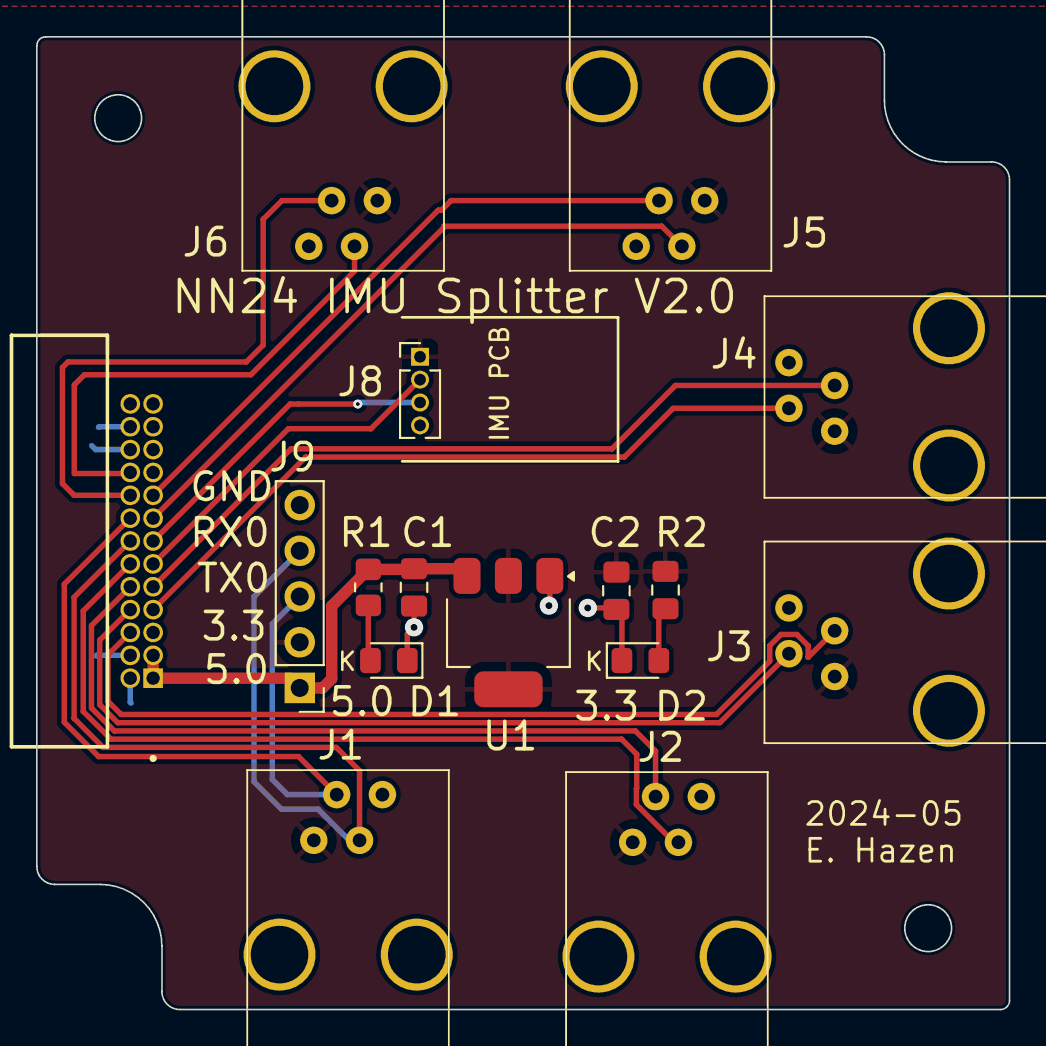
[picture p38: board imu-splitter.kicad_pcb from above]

Board: 2 copper layers, 54.0 x 54.0 mm, 16 parts (0 on the bottom side), 19 nets.

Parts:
C1: 10uF; C_0805_2012Metric_Pad1.18x1.45mm_HandSolder
C2: 22uF; C_0805_2012Metric_Pad1.18x1.45mm_HandSolder
D1, D2: LED; LED_0805_2012Metric_Pad1.15x1.40mm_HandSolder
J1, J2, J3, J4, J5, J6: 4P4C; A-2004-3-4-LP
J7: 3220-26-0200-00; SAMTEC_SHF-113-01-L-D-RA
J8: Conn_01x04; PinHeader_1x04_P1.27mm_Vertical
J9: Conn_01x05; PinHeader_1x05_P2.54mm_Vertical
R1: 1.5k; R_0805_2012Metric_Pad1.20x1.40mm_HandSolder
R2: 510; C_0805_2012Metric_Pad1.18x1.45mm_HandSolder
U1: AP2114H-3.3TRG1; SOT-223-3_TabPin2

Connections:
+3.3V: C2.1, J1.1, J2.1, J3.1, J4.1, J5.1, J6.1, J8.1, J9.2, R2.1, U1.2 (VO)
+5V: C1.1, J7.1, J7.3, J9.1, R1.1, U1.3 (VI)
/RX0: J1.3, J7.14, J9.4
/RX1: J2.3, J7.12
/RX2: J3.3, J7.6
/RX3: J4.3, J7.9
/RX4: J5.3, J7.17
/RX5: J6.3, J7.18
/RX6: J7.13, J8.3
/TX0: J1.2, J7.16, J9.3
/TX1: J2.2, J7.10
/TX2: J3.2, J7.8
/TX3: J4.2, J7.7
/TX4: J5.2, J7.15
/TX5: J6.2, J7.20
/TX6: J7.11, J8.2
GND: C1.2, C2.2, D1.1 (K), D2.1 (K), J1.4, J2.4, J3.4, J4.4, J5.4, J6.4, J7.2, J7.4, J7.22, J7.24, J8.4, J9.5, U1.1 (GND)
unnamed: D1.2 (A), R1.2
unnamed: D2.2 (A), R2.2

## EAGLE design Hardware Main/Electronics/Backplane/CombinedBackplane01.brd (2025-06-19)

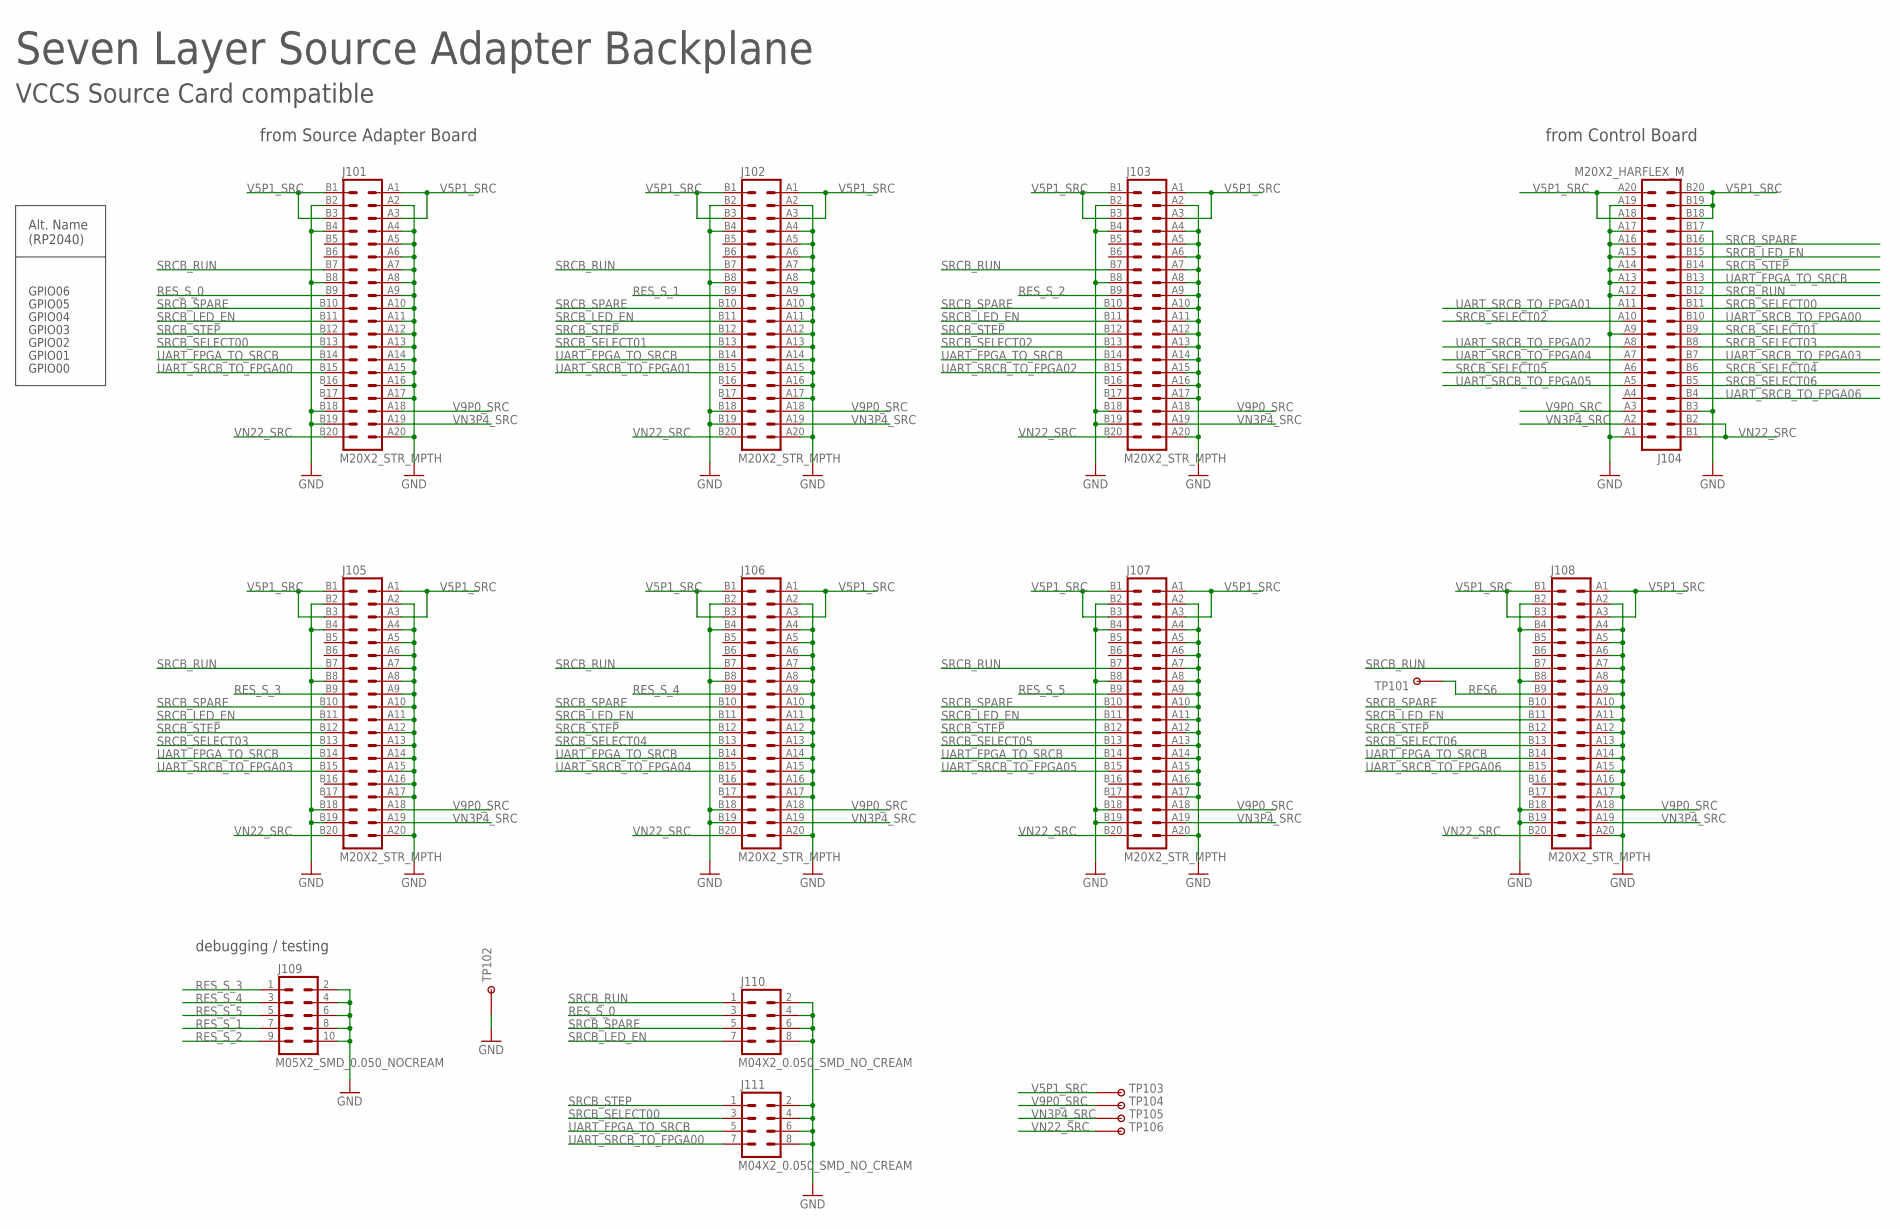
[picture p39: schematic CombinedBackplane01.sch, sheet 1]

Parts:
J101, J102, J103, J105, J106, J107, J108: M20X2_STR_MPTH; M20X2_HARFLEX_F_STR_MPTH
J104: M20X2_HARFLEX_M
J109: M05X2_SMD_0.050_NOCREAM; M05X2_0.050_SMD_NO_CREAM
J110, J111: M04X2_0.050_SMD_NO_CREAM
TP101, TP103, TP104, TP105, TP106: TESTPOINT_ROUND; TESTPAD_ROUND
TP102: TESTPOINTTUR; TURRET

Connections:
GND_SRC: J101.A2 (4), J101.A4 (8), J101.A5 (10), J101.A6 (12), J101.A7 (14), J101.A8 (16), J101.A9 (18), J101.A10 (20), J101.A11 (22), J101.A12 (24), J101.A13 (26), J101.A14 (28), J101.A15 (30), J101.A16 (32), J101.A17 (34), J101.A20 (40), J101.B2 (3), J101.B4 (7), J101.B8 (15), J101.B18 (35), J101.B19 (37), J102.A2 (4), J102.A4 (8), J102.A5 (10), J102.A6 (12), J102.A7 (14), J102.A8 (16), J102.A9 (18), J102.A10 (20), J102.A11 (22), J102.A12 (24), J102.A13 (26), J102.A14 (28), J102.A15 (30), J102.A16 (32), J102.A17 (34), J102.A20 (40), J102.B2 (3), J102.B4 (7), J102.B8 (15), J102.B18 (35), J102.B19 (37), J103.A2 (4), J103.A4 (8), J103.A5 (10), J103.A6 (12), J103.A7 (14), J103.A8 (16), J103.A9 (18), J103.A10 (20), J103.A11 (22), J103.A12 (24), J103.A13 (26), J103.A14 (28), J103.A15 (30), J103.A16 (32), J103.A17 (34), J103.A20 (40), J103.B2 (3), J103.B4 (7), J103.B8 (15), J103.B18 (35), J103.B19 (37), J104.A1 (2), J104.A9 (18), J104.A12 (24), J104.A13 (26), J104.A14 (28), J104.A15 (30), J104.A16 (32), J104.A17 (34), J104.A19 (38), J104.B3 (5), J104.B17 (33), J105.A2 (4), J105.A4 (8), J105.A5 (10), J105.A6 (12), J105.A7 (14), J105.A8 (16), J105.A9 (18), J105.A10 (20), J105.A11 (22), J105.A12 (24), J105.A13 (26), J105.A14 (28), J105.A15 (30), J105.A16 (32), J105.A17 (34), J105.A20 (40), J105.B2 (3), J105.B4 (7), J105.B8 (15), J105.B18 (35), J105.B19 (37), J106.A2 (4), J106.A4 (8), J106.A5 (10), J106.A6 (12), J106.A7 (14), J106.A8 (16), J106.A9 (18), J106.A10 (20), J106.A11 (22), J106.A12 (24), J106.A13 (26), J106.A14 (28), J106.A15 (30), J106.A16 (32), J106.A17 (34), J106.A20 (40), J106.B2 (3), J106.B4 (7), J106.B8 (15), J106.B18 (35), J106.B19 (37), J107.A2 (4), J107.A4 (8), J107.A5 (10), J107.A6 (12), J107.A7 (14), J107.A8 (16), J107.A9 (18), J107.A10 (20), J107.A11 (22), J107.A12 (24), J107.A13 (26), J107.A14 (28), J107.A15 (30), J107.A16 (32), J107.A17 (34), J107.A20 (40), J107.B2 (3), J107.B4 (7), J107.B8 (15), J107.B18 (35), J107.B19 (37), J108.A2 (4), J108.A4 (8), J108.A5 (10), J108.A6 (12), J108.A7 (14), J108.A8 (16), J108.A9 (18), J108.A10 (20), J108.A11 (22), J108.A12 (24), J108.A13 (26), J108.A14 (28), J108.A15 (30), J108.A16 (32), J108.A17 (34), J108.A20 (40), J108.B2 (3), J108.B4 (7), J108.B8 (15), J108.B18 (35), J108.B19 (37), J109.2, J109.4, J109.6, J109.8, J109.10, J110.2, J110.4, J110.6, J110.8, J111.2, J111.4, J111.6, J111.8, TP102.P$1
RES6: J108.B9 (17), TP101.P$1
RES_S_0: J101.B9 (17), J110.3
RES_S_1: J102.B9 (17), J109.7
RES_S_2: J103.B9 (17), J109.9
RES_S_3: J105.B9 (17), J109.1
RES_S_4: J106.B9 (17), J109.3
RES_S_5: J107.B9 (17), J109.5
SRCB_LED_EN: J101.B11 (21), J102.B11 (21), J103.B11 (21), J104.B15 (29), J105.B11 (21), J106.B11 (21), J107.B11 (21), J108.B11 (21), J110.7
SRCB_RUN: J101.B7 (13), J102.B7 (13), J103.B7 (13), J104.B12 (23), J105.B7 (13), J106.B7 (13), J107.B7 (13), J108.B7 (13), J110.1
SRCB_SELECT00: J101.B13 (25), J104.B11 (21), J111.3
SRCB_SELECT01: J102.B13 (25), J104.B9 (17)
SRCB_SELECT02: J103.B13 (25), J104.A10 (20)
SRCB_SELECT03: J104.B8 (15), J105.B13 (25)
SRCB_SELECT04: J104.B6 (11), J106.B13 (25)
SRCB_SELECT05: J104.A6 (12), J107.B13 (25)
SRCB_SELECT06: J104.B5 (9), J108.B13 (25)
SRCB_SPARE: J101.B10 (19), J102.B10 (19), J103.B10 (19), J104.B16 (31), J105.B10 (19), J106.B10 (19), J107.B10 (19), J108.B10 (19), J110.5
SRCB_STEP: J101.B12 (23), J102.B12 (23), J103.B12 (23), J104.B14 (27), J105.B12 (23), J106.B12 (23), J107.B12 (23), J108.B12 (23), J111.1
UART_FPGA_TO_SRCB: J101.B14 (27), J102.B14 (27), J103.B14 (27), J104.B13 (25), J105.B14 (27), J106.B14 (27), J107.B14 (27), J108.B14 (27), J111.5
UART_SRCB_TO_FPGA00: J101.B15 (29), J104.B10 (19), J111.7
UART_SRCB_TO_FPGA01: J102.B15 (29), J104.A11 (22)
UART_SRCB_TO_FPGA02: J103.B15 (29), J104.A8 (16)
UART_SRCB_TO_FPGA03: J104.B7 (13), J105.B15 (29)
UART_SRCB_TO_FPGA04: J104.A7 (14), J106.B15 (29)
UART_SRCB_TO_FPGA05: J104.A5 (10), J107.B15 (29)
UART_SRCB_TO_FPGA06: J104.B4 (7), J108.B15 (29)
V5P1_SRC: J101.A1 (2), J101.A3 (6), J101.B1 (1), J101.B3 (5), J102.A1 (2), J102.A3 (6), J102.B1 (1), J102.B3 (5), J103.A1 (2), J103.A3 (6), J103.B1 (1), J103.B3 (5), J104.A18 (36), J104.A20 (40), J104.B18 (35), J104.B19 (37), J104.B20 (39), J105.A1 (2), J105.A3 (6), J105.B1 (1), J105.B3 (5), J106.A1 (2), J106.A3 (6), J106.B1 (1), J106.B3 (5), J107.A1 (2), J107.A3 (6), J107.B1 (1), J107.B3 (5), J108.A1 (2), J108.A3 (6), J108.B1 (1), J108.B3 (5), TP103.P$1
V9P0_SRC: J101.A18 (36), J102.A18 (36), J103.A18 (36), J104.A3 (6), J105.A18 (36), J106.A18 (36), J107.A18 (36), J108.A18 (36), TP104.P$1
VN3P4_SRC: J101.A19 (38), J102.A19 (38), J103.A19 (38), J104.A2 (4), J105.A19 (38), J106.A19 (38), J107.A19 (38), J108.A19 (38), TP105.P$1
VN22_SRC: J101.B20 (39), J102.B20 (39), J103.B20 (39), J104.B1 (1), J104.B2 (3), J105.B20 (39), J106.B20 (39), J107.B20 (39), J108.B20 (39), TP106.P$1

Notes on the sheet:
Seven Layer Source Adapter Backplane
from Source Adapter Board
from Control Board
GPIO00
GPIO01
GPIO02
GPIO03
GPIO04
GPIO05
GPIO06
debugging / testing
Alt. Name (RP2040)
VCCS Source Card compatible

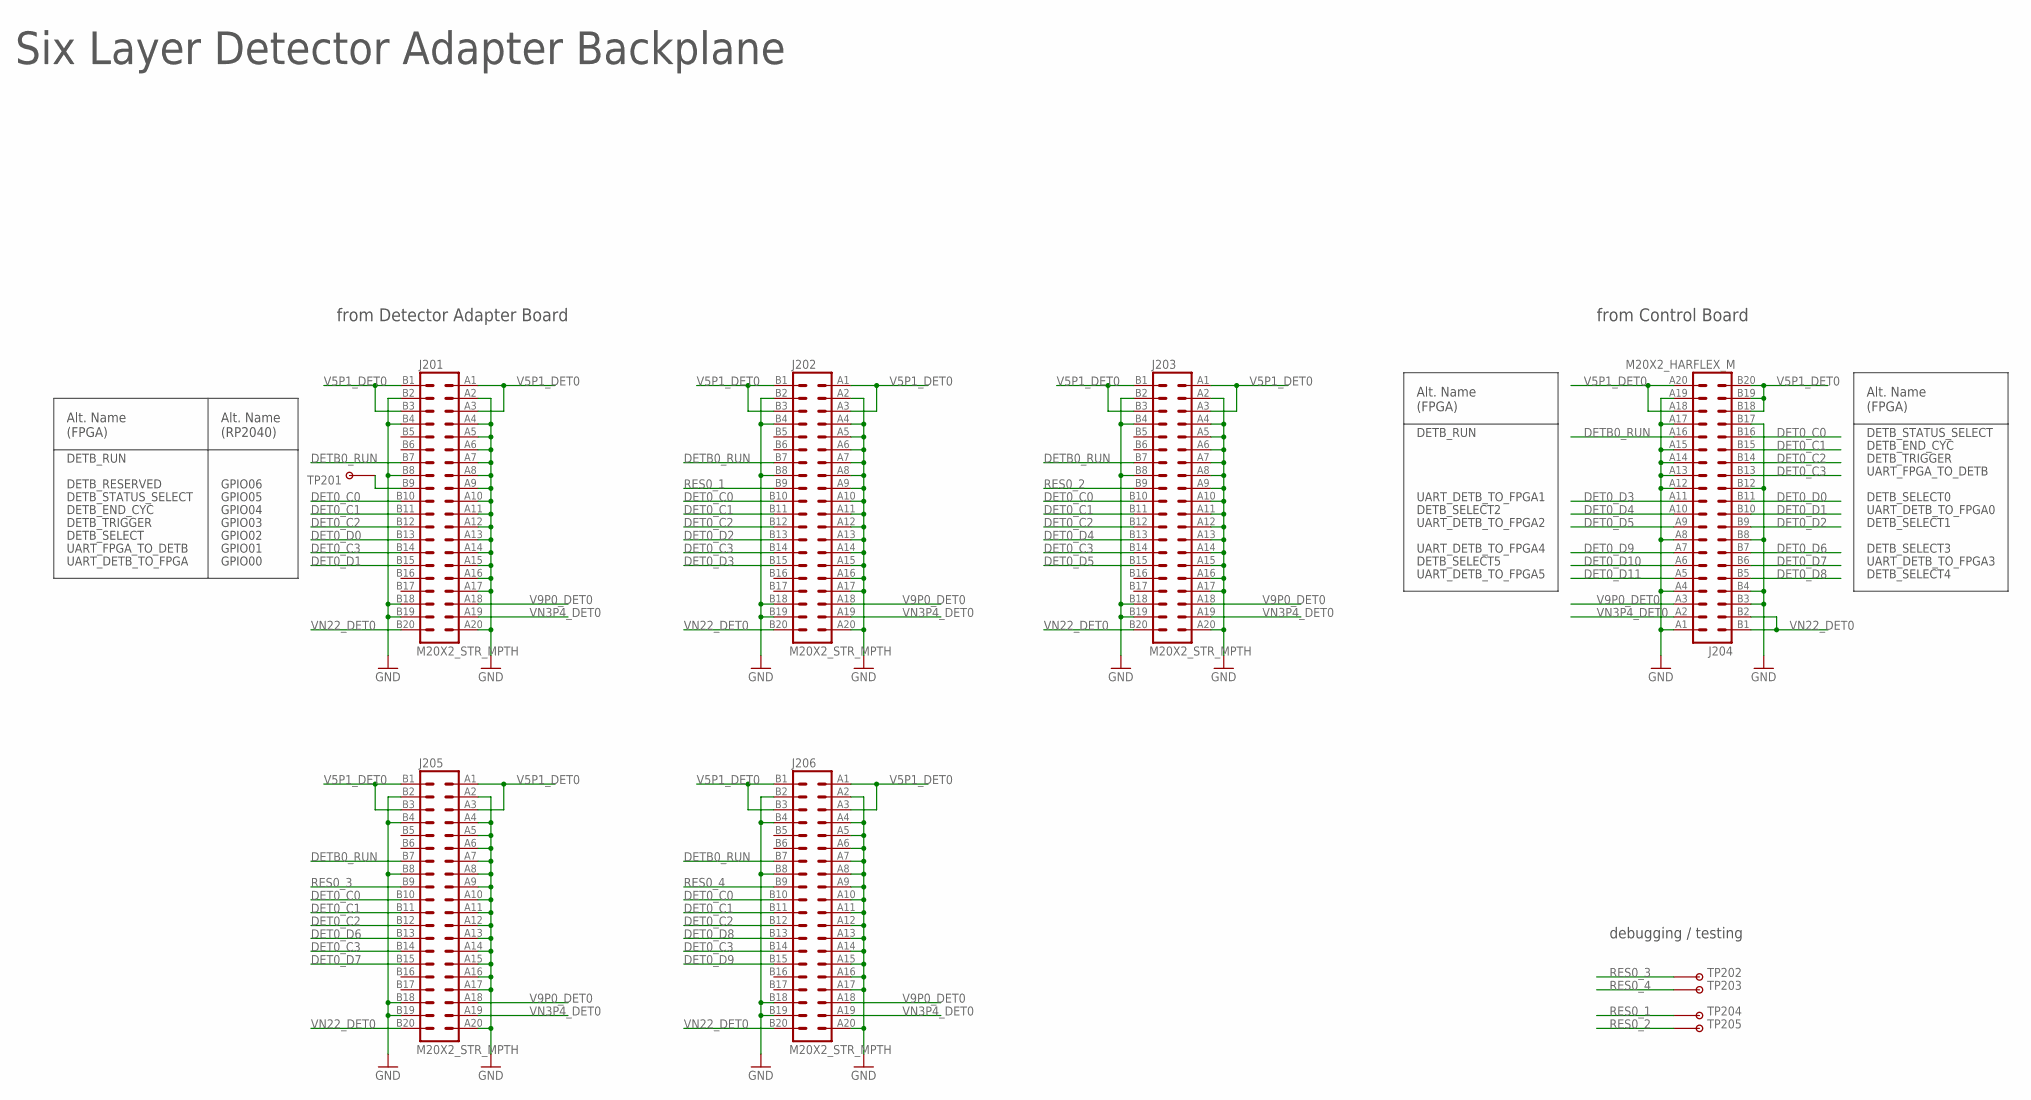
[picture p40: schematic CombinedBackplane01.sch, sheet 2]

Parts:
J201, J202, J203, J205, J206: M20X2_STR_MPTH; M20X2_HARFLEX_F_STR_MPTH
J204: M20X2_HARFLEX_M
TP201, TP202, TP203, TP204, TP205: TESTPOINT_ROUND; TESTPAD_ROUND

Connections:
DET0_C0: J201.B10 (19), J202.B10 (19), J203.B10 (19), J204.B16 (31), J205.B10 (19), J206.B10 (19)
DET0_C1: J201.B11 (21), J202.B11 (21), J203.B11 (21), J204.B15 (29), J205.B11 (21), J206.B11 (21)
DET0_C2: J201.B12 (23), J202.B12 (23), J203.B12 (23), J204.B14 (27), J205.B12 (23), J206.B12 (23)
DET0_C3: J201.B14 (27), J202.B14 (27), J203.B14 (27), J204.B13 (25), J205.B14 (27), J206.B14 (27)
DET0_D0: J201.B13 (25), J204.B11 (21)
DET0_D1: J201.B15 (29), J204.B10 (19)
DET0_D2: J202.B13 (25), J204.B9 (17)
DET0_D3: J202.B15 (29), J204.A11 (22)
DET0_D4: J203.B13 (25), J204.A10 (20)
DET0_D5: J203.B15 (29), J204.A9 (18)
DET0_D6: J204.B7 (13), J205.B13 (25)
DET0_D7: J204.B6 (11), J205.B15 (29)
DET0_D8: J204.B5 (9), J206.B13 (25)
DET0_D9: J204.A7 (14), J206.B15 (29)
DET0_D10: J204.A6 (12)
DET0_D11: J204.A5 (10)
DETB0_RUN: J201.B7 (13), J202.B7 (13), J203.B7 (13), J204.A16 (32), J205.B7 (13), J206.B7 (13)
GND: J201.A2 (4), J201.A4 (8), J201.A5 (10), J201.A6 (12), J201.A7 (14), J201.A8 (16), J201.A9 (18), J201.A10 (20), J201.A11 (22), J201.A12 (24), J201.A13 (26), J201.A14 (28), J201.A15 (30), J201.A16 (32), J201.A17 (34), J201.A20 (40), J201.B2 (3), J201.B4 (7), J201.B8 (15), J201.B18 (35), J201.B19 (37), J202.A2 (4), J202.A4 (8), J202.A5 (10), J202.A6 (12), J202.A7 (14), J202.A8 (16), J202.A9 (18), J202.A10 (20), J202.A11 (22), J202.A12 (24), J202.A13 (26), J202.A14 (28), J202.A15 (30), J202.A16 (32), J202.A17 (34), J202.A20 (40), J202.B2 (3), J202.B4 (7), J202.B8 (15), J202.B18 (35), J202.B19 (37), J203.A2 (4), J203.A4 (8), J203.A5 (10), J203.A6 (12), J203.A7 (14), J203.A8 (16), J203.A9 (18), J203.A10 (20), J203.A11 (22), J203.A12 (24), J203.A13 (26), J203.A14 (28), J203.A15 (30), J203.A16 (32), J203.A17 (34), J203.A20 (40), J203.B2 (3), J203.B4 (7), J203.B8 (15), J203.B18 (35), J203.B19 (37), J204.A1 (2), J204.A4 (8), J204.A8 (16), J204.A12 (24), J204.A13 (26), J204.A14 (28), J204.A15 (30), J204.A17 (34), J204.A19 (38), J204.B3 (5), J204.B4 (7), J204.B8 (15), J204.B12 (23), J204.B17 (33), J205.A2 (4), J205.A4 (8), J205.A5 (10), J205.A6 (12), J205.A7 (14), J205.A8 (16), J205.A9 (18), J205.A10 (20), J205.A11 (22), J205.A12 (24), J205.A13 (26), J205.A14 (28), J205.A15 (30), J205.A16 (32), J205.A17 (34), J205.A20 (40), J205.B2 (3), J205.B4 (7), J205.B8 (15), J205.B18 (35), J205.B19 (37), J206.A2 (4), J206.A4 (8), J206.A5 (10), J206.A6 (12), J206.A7 (14), J206.A8 (16), J206.A9 (18), J206.A10 (20), J206.A11 (22), J206.A12 (24), J206.A13 (26), J206.A14 (28), J206.A15 (30), J206.A16 (32), J206.A17 (34), J206.A20 (40), J206.B2 (3), J206.B4 (7), J206.B8 (15), J206.B18 (35), J206.B19 (37); also elsewhere on the board
unnamed: J201.B9 (17), TP201.P$1
RES0_1: J202.B9 (17), TP204.P$1
RES0_2: J203.B9 (17), TP205.P$1
RES0_3: J205.B9 (17), TP202.P$1
RES0_4: J206.B9 (17), TP203.P$1
V5P1_DET0: J201.A1 (2), J201.A3 (6), J201.B1 (1), J201.B3 (5), J202.A1 (2), J202.A3 (6), J202.B1 (1), J202.B3 (5), J203.A1 (2), J203.A3 (6), J203.B1 (1), J203.B3 (5), J204.A18 (36), J204.A20 (40), J204.B18 (35), J204.B19 (37), J204.B20 (39), J205.A1 (2), J205.A3 (6), J205.B1 (1), J205.B3 (5), J206.A1 (2), J206.A3 (6), J206.B1 (1), J206.B3 (5)
V9P0_DET0: J201.A18 (36), J202.A18 (36), J203.A18 (36), J204.A3 (6), J205.A18 (36), J206.A18 (36)
VN3P4_DET0: J201.A19 (38), J202.A19 (38), J203.A19 (38), J204.A2 (4), J205.A19 (38), J206.A19 (38)
VN22_DET0: J201.B20 (39), J202.B20 (39), J203.B20 (39), J204.B1 (1), J204.B2 (3), J205.B20 (39), J206.B20 (39)

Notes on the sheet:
Six Layer Detector Adapter Backplane
from Detector Adapter Board
from Control Board
GPIO00
GPIO01
GPIO02
GPIO03
GPIO04
GPIO05
GPIO06
UART_DETB_TO_FPGA
UART_FPGA_TO_DETB
DETB_SELECT
DETB_TRIGGER
DETB_END_CYC
DETB_STATUS_SELECT
DETB_RESERVED
DETB_RUN
debugging / testing
UART_DETB_TO_FPGA0
DETB_SELECT0
DETB_SELECT1
DETB_SELECT2
DETB_SELECT5
DETB_SELECT3
DETB_SELECT4
UART_DETB_TO_FPGA1
UART_DETB_TO_FPGA2
UART_DETB_TO_FPGA4
UART_DETB_TO_FPGA5
UART_DETB_TO_FPGA3
Alt. Name (FPGA)
Alt. Name (RP2040)

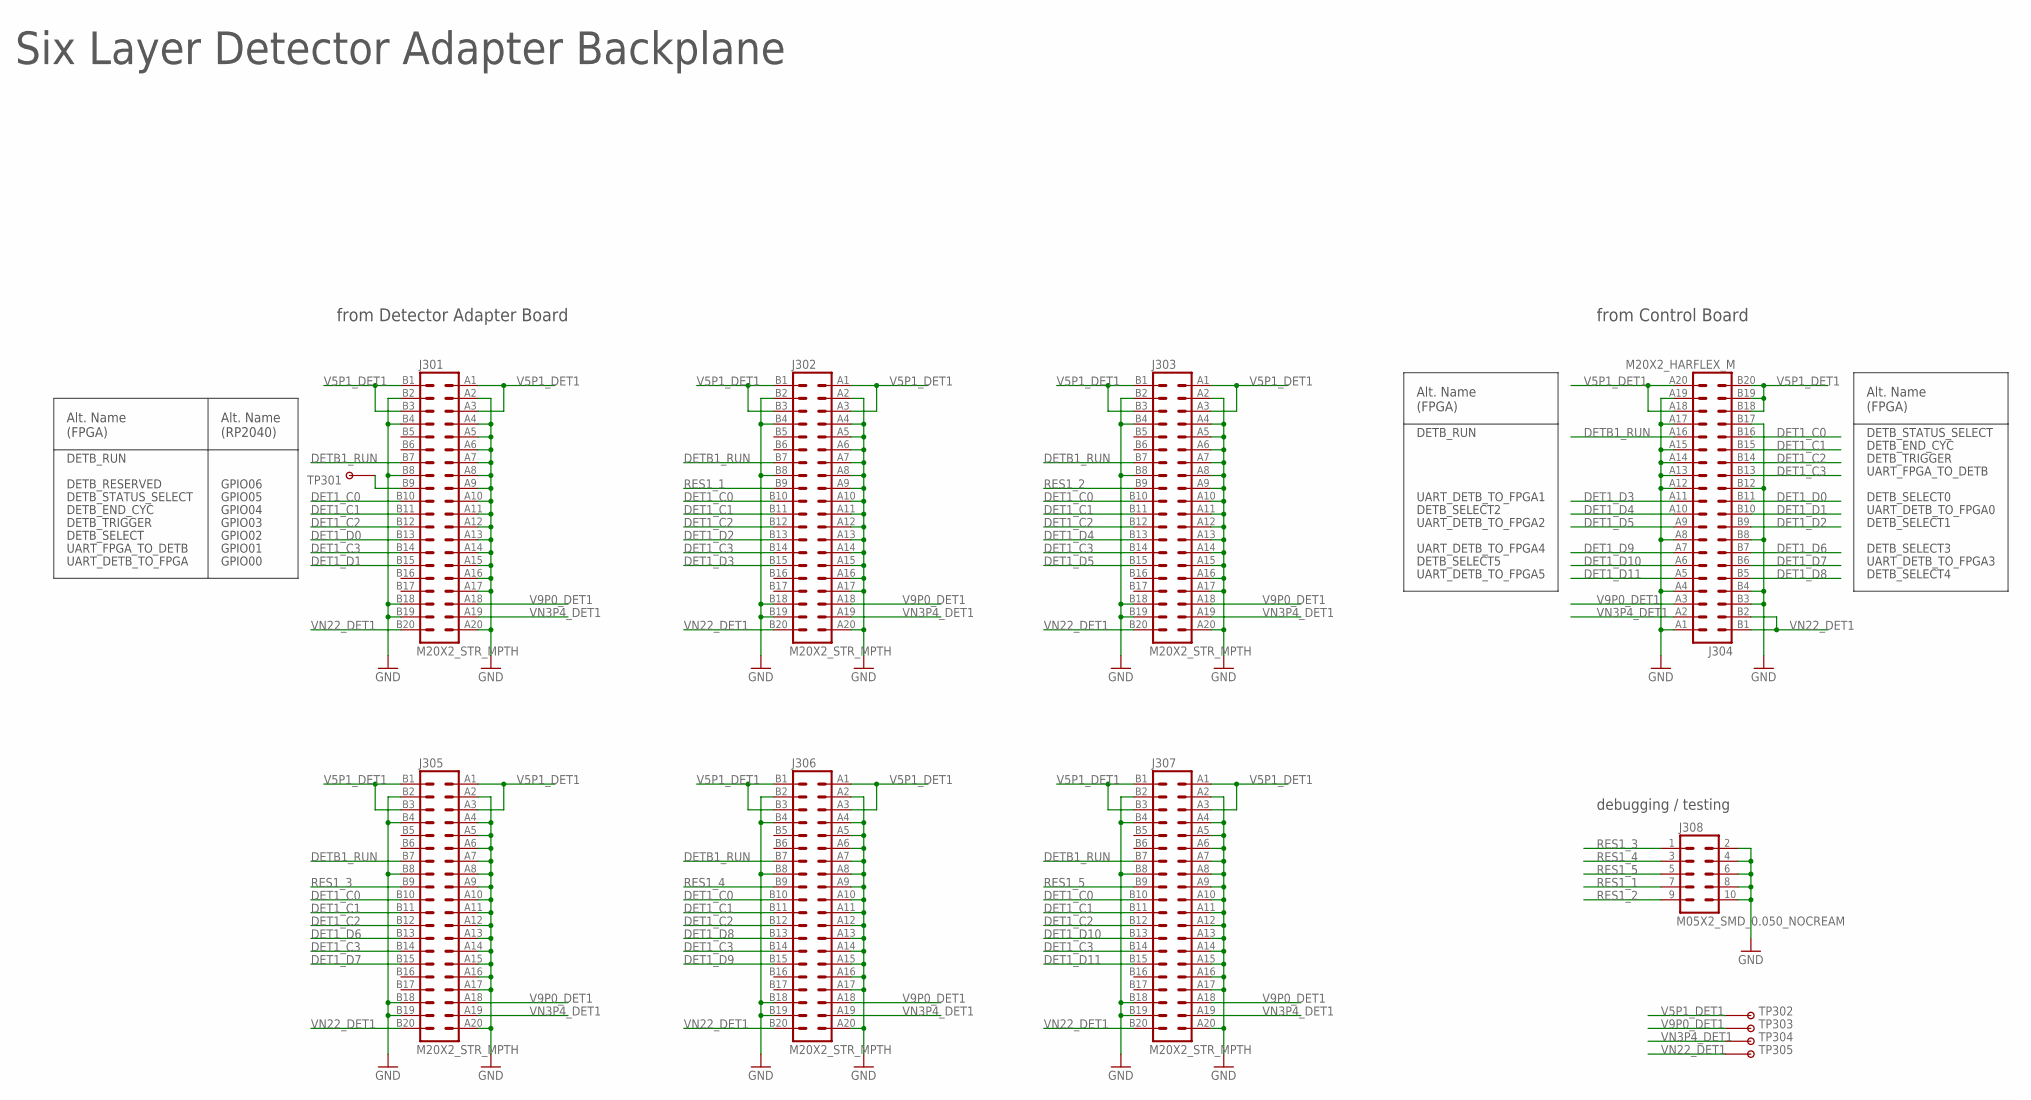
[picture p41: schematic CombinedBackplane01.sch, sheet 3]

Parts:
J301, J302, J303, J305, J306, J307: M20X2_STR_MPTH; M20X2_HARFLEX_F_STR_MPTH
J304: M20X2_HARFLEX_M
J308: M05X2_SMD_0.050_NOCREAM; M05X2_0.050_SMD_NO_CREAM
TP301, TP302, TP303, TP304, TP305: TESTPOINT_ROUND; TESTPAD_ROUND

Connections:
DET1_C0: J301.B10 (19), J302.B10 (19), J303.B10 (19), J304.B16 (31), J305.B10 (19), J306.B10 (19), J307.B10 (19)
DET1_C1: J301.B11 (21), J302.B11 (21), J303.B11 (21), J304.B15 (29), J305.B11 (21), J306.B11 (21), J307.B11 (21)
DET1_C2: J301.B12 (23), J302.B12 (23), J303.B12 (23), J304.B14 (27), J305.B12 (23), J306.B12 (23), J307.B12 (23)
DET1_C3: J301.B14 (27), J302.B14 (27), J303.B14 (27), J304.B13 (25), J305.B14 (27), J306.B14 (27), J307.B14 (27)
DET1_D0: J301.B13 (25), J304.B11 (21)
DET1_D1: J301.B15 (29), J304.B10 (19)
DET1_D2: J302.B13 (25), J304.B9 (17)
DET1_D3: J302.B15 (29), J304.A11 (22)
DET1_D4: J303.B13 (25), J304.A10 (20)
DET1_D5: J303.B15 (29), J304.A9 (18)
DET1_D6: J304.B7 (13), J305.B13 (25)
DET1_D7: J304.B6 (11), J305.B15 (29)
DET1_D8: J304.B5 (9), J306.B13 (25)
DET1_D9: J304.A7 (14), J306.B15 (29)
DET1_D10: J304.A6 (12), J307.B13 (25)
DET1_D11: J304.A5 (10), J307.B15 (29)
DETB1_RUN: J301.B7 (13), J302.B7 (13), J303.B7 (13), J304.A16 (32), J305.B7 (13), J306.B7 (13), J307.B7 (13)
GND: J301.A2 (4), J301.A4 (8), J301.A5 (10), J301.A6 (12), J301.A7 (14), J301.A8 (16), J301.A9 (18), J301.A10 (20), J301.A11 (22), J301.A12 (24), J301.A13 (26), J301.A14 (28), J301.A15 (30), J301.A16 (32), J301.A17 (34), J301.A20 (40), J301.B2 (3), J301.B4 (7), J301.B8 (15), J301.B18 (35), J301.B19 (37), J302.A2 (4), J302.A4 (8), J302.A5 (10), J302.A6 (12), J302.A7 (14), J302.A8 (16), J302.A9 (18), J302.A10 (20), J302.A11 (22), J302.A12 (24), J302.A13 (26), J302.A14 (28), J302.A15 (30), J302.A16 (32), J302.A17 (34), J302.A20 (40), J302.B2 (3), J302.B4 (7), J302.B8 (15), J302.B18 (35), J302.B19 (37), J303.A2 (4), J303.A4 (8), J303.A5 (10), J303.A6 (12), J303.A7 (14), J303.A8 (16), J303.A9 (18), J303.A10 (20), J303.A11 (22), J303.A12 (24), J303.A13 (26), J303.A14 (28), J303.A15 (30), J303.A16 (32), J303.A17 (34), J303.A20 (40), J303.B2 (3), J303.B4 (7), J303.B8 (15), J303.B18 (35), J303.B19 (37), J304.A1 (2), J304.A4 (8), J304.A8 (16), J304.A12 (24), J304.A13 (26), J304.A14 (28), J304.A15 (30), J304.A17 (34), J304.A19 (38), J304.B3 (5), J304.B4 (7), J304.B8 (15), J304.B12 (23), J304.B17 (33), J305.A2 (4), J305.A4 (8), J305.A5 (10), J305.A6 (12), J305.A7 (14), J305.A8 (16), J305.A9 (18), J305.A10 (20), J305.A11 (22), J305.A12 (24), J305.A13 (26), J305.A14 (28), J305.A15 (30), J305.A16 (32), J305.A17 (34), J305.A20 (40), J305.B2 (3), J305.B4 (7), J305.B8 (15), J305.B18 (35), J305.B19 (37), J306.A2 (4), J306.A4 (8), J306.A5 (10), J306.A6 (12), J306.A7 (14), J306.A8 (16), J306.A9 (18), J306.A10 (20), J306.A11 (22), J306.A12 (24), J306.A13 (26), J306.A14 (28), J306.A15 (30), J306.A16 (32), J306.A17 (34), J306.A20 (40), J306.B2 (3), J306.B4 (7), J306.B8 (15), J306.B18 (35), J306.B19 (37), J307.A2 (4), J307.A4 (8), J307.A5 (10), J307.A6 (12), J307.A7 (14), J307.A8 (16), J307.A9 (18), J307.A10 (20), J307.A11 (22), J307.A12 (24), J307.A13 (26), J307.A14 (28), J307.A15 (30), J307.A16 (32), J307.A17 (34), J307.A20 (40), J307.B2 (3), J307.B4 (7), J307.B8 (15), J307.B18 (35), J307.B19 (37), J308.2, J308.4, J308.6, J308.8, J308.10; also elsewhere on the board
unnamed: J301.B9 (17), TP301.P$1
RES1_1: J302.B9 (17), J308.7
RES1_2: J303.B9 (17), J308.9
RES1_3: J305.B9 (17), J308.1
RES1_4: J306.B9 (17), J308.3
RES1_5: J307.B9 (17), J308.5
V5P1_DET1: J301.A1 (2), J301.A3 (6), J301.B1 (1), J301.B3 (5), J302.A1 (2), J302.A3 (6), J302.B1 (1), J302.B3 (5), J303.A1 (2), J303.A3 (6), J303.B1 (1), J303.B3 (5), J304.A18 (36), J304.A20 (40), J304.B18 (35), J304.B19 (37), J304.B20 (39), J305.A1 (2), J305.A3 (6), J305.B1 (1), J305.B3 (5), J306.A1 (2), J306.A3 (6), J306.B1 (1), J306.B3 (5), J307.A1 (2), J307.A3 (6), J307.B1 (1), J307.B3 (5), TP302.P$1
V9P0_DET1: J301.A18 (36), J302.A18 (36), J303.A18 (36), J304.A3 (6), J305.A18 (36), J306.A18 (36), J307.A18 (36), TP303.P$1
VN3P4_DET1: J301.A19 (38), J302.A19 (38), J303.A19 (38), J304.A2 (4), J305.A19 (38), J306.A19 (38), J307.A19 (38), TP304.P$1
VN22_DET1: J301.B20 (39), J302.B20 (39), J303.B20 (39), J304.B1 (1), J304.B2 (3), J305.B20 (39), J306.B20 (39), J307.B20 (39), TP305.P$1

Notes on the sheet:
Six Layer Detector Adapter Backplane
from Detector Adapter Board
from Control Board
GPIO00
GPIO01
GPIO02
GPIO03
GPIO04
GPIO05
GPIO06
UART_DETB_TO_FPGA
UART_FPGA_TO_DETB
DETB_SELECT
DETB_TRIGGER
DETB_END_CYC
DETB_STATUS_SELECT
DETB_RESERVED
DETB_RUN
debugging / testing
UART_DETB_TO_FPGA0
DETB_SELECT0
DETB_SELECT1
DETB_SELECT2
DETB_SELECT5
DETB_SELECT3
DETB_SELECT4
UART_DETB_TO_FPGA1
UART_DETB_TO_FPGA2
UART_DETB_TO_FPGA4
UART_DETB_TO_FPGA5
UART_DETB_TO_FPGA3
Alt. Name (FPGA)
Alt. Name (RP2040)

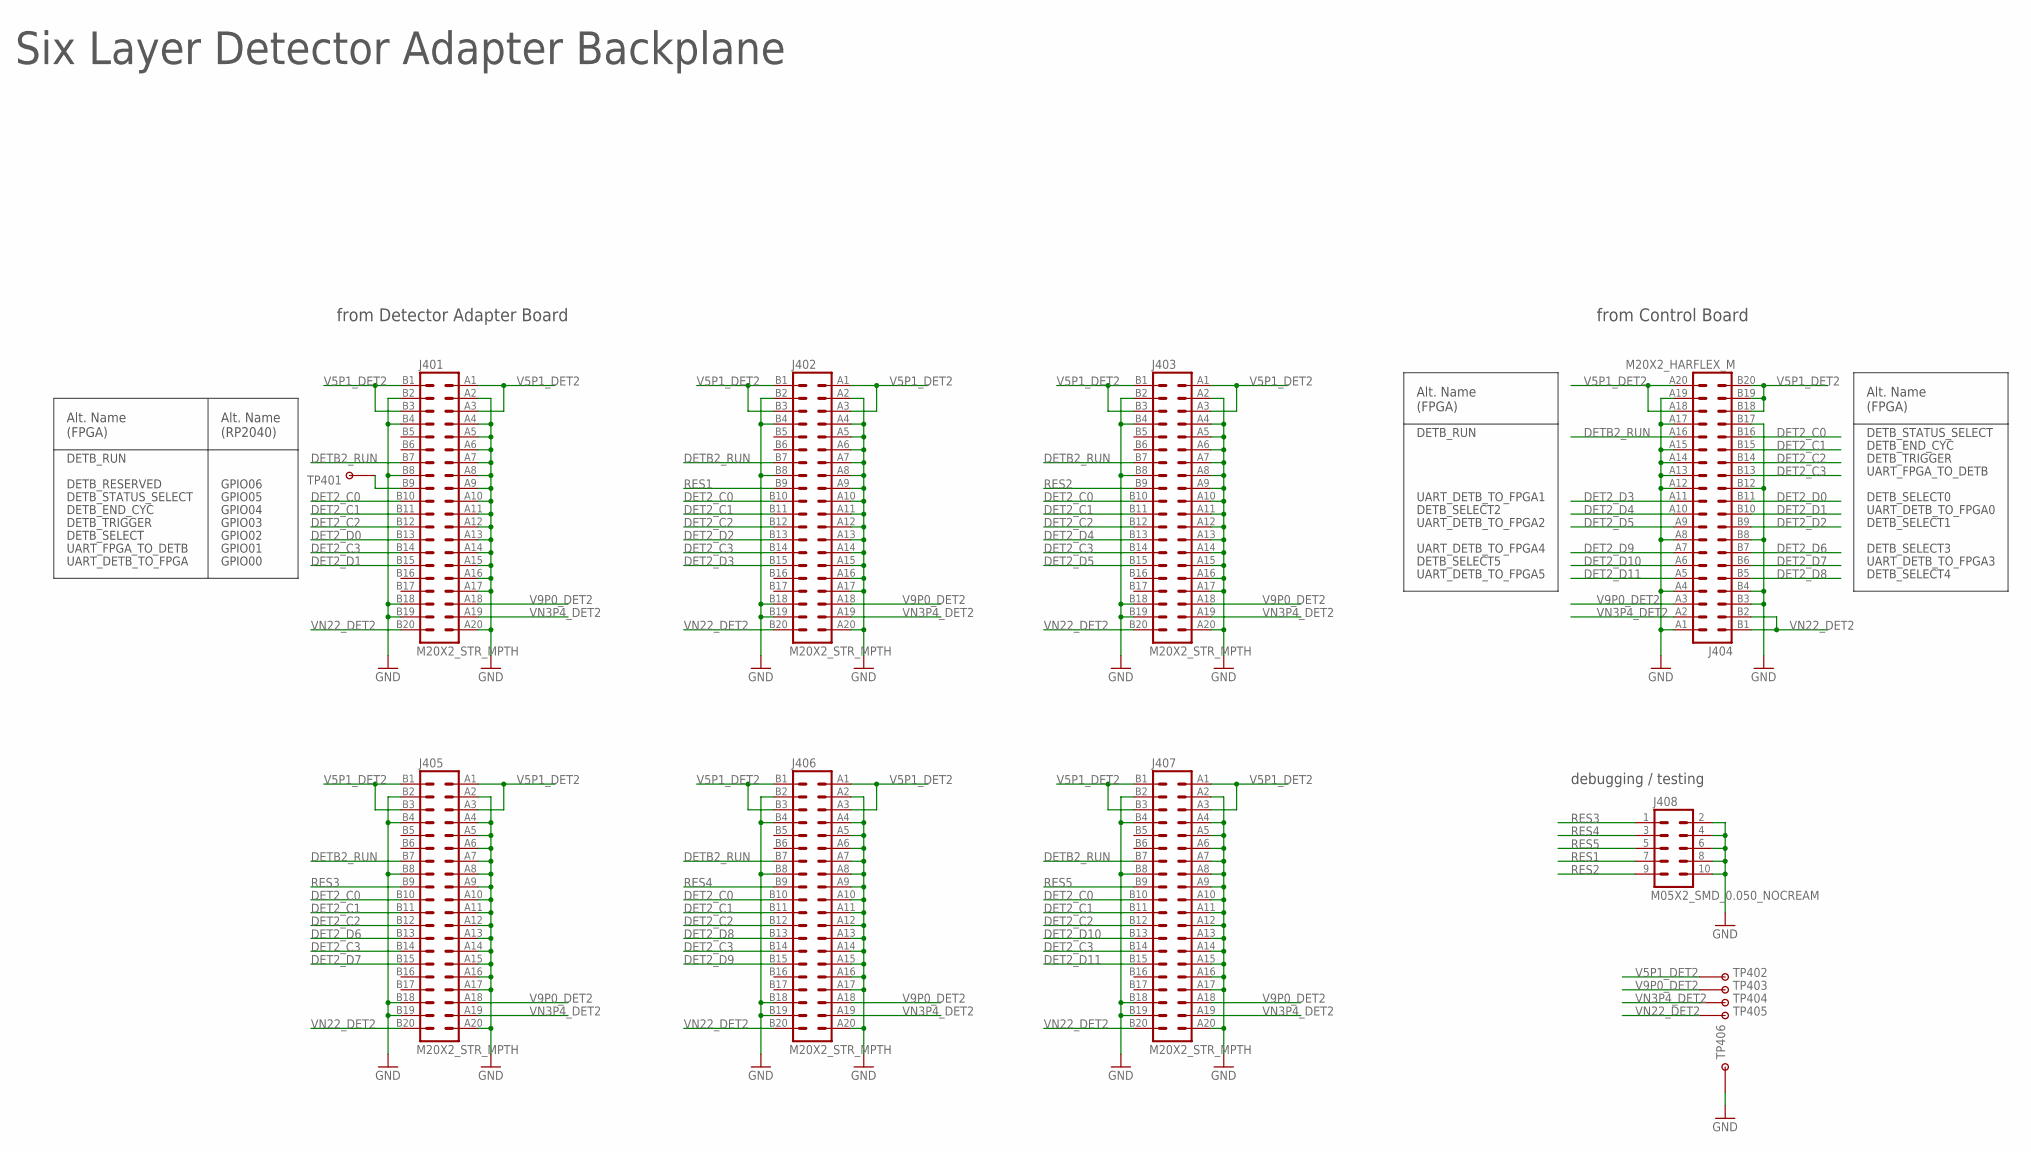
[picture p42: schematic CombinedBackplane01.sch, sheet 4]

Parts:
J401, J402, J403, J405, J406, J407: M20X2_STR_MPTH; M20X2_HARFLEX_F_STR_MPTH
J404: M20X2_HARFLEX_M
J408: M05X2_SMD_0.050_NOCREAM; M05X2_0.050_SMD_NO_CREAM
TP401, TP402, TP403, TP404, TP405: TESTPOINT_ROUND; TESTPAD_ROUND
TP406: TESTPOINTTUR; TURRET

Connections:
DET2_C0: J401.B10 (19), J402.B10 (19), J403.B10 (19), J404.B16 (31), J405.B10 (19), J406.B10 (19), J407.B10 (19)
DET2_C1: J401.B11 (21), J402.B11 (21), J403.B11 (21), J404.B15 (29), J405.B11 (21), J406.B11 (21), J407.B11 (21)
DET2_C2: J401.B12 (23), J402.B12 (23), J403.B12 (23), J404.B14 (27), J405.B12 (23), J406.B12 (23), J407.B12 (23)
DET2_C3: J401.B14 (27), J402.B14 (27), J403.B14 (27), J404.B13 (25), J405.B14 (27), J406.B14 (27), J407.B14 (27)
DET2_D0: J401.B13 (25), J404.B11 (21)
DET2_D1: J401.B15 (29), J404.B10 (19)
DET2_D2: J402.B13 (25), J404.B9 (17)
DET2_D3: J402.B15 (29), J404.A11 (22)
DET2_D4: J403.B13 (25), J404.A10 (20)
DET2_D5: J403.B15 (29), J404.A9 (18)
DET2_D6: J404.B7 (13), J405.B13 (25)
DET2_D7: J404.B6 (11), J405.B15 (29)
DET2_D8: J404.B5 (9), J406.B13 (25)
DET2_D9: J404.A7 (14), J406.B15 (29)
DET2_D10: J404.A6 (12), J407.B13 (25)
DET2_D11: J404.A5 (10), J407.B15 (29)
DETB2_RUN: J401.B7 (13), J402.B7 (13), J403.B7 (13), J404.A16 (32), J405.B7 (13), J406.B7 (13), J407.B7 (13)
GND: J401.A2 (4), J401.A4 (8), J401.A5 (10), J401.A6 (12), J401.A7 (14), J401.A8 (16), J401.A9 (18), J401.A10 (20), J401.A11 (22), J401.A12 (24), J401.A13 (26), J401.A14 (28), J401.A15 (30), J401.A16 (32), J401.A17 (34), J401.A20 (40), J401.B2 (3), J401.B4 (7), J401.B8 (15), J401.B18 (35), J401.B19 (37), J402.A2 (4), J402.A4 (8), J402.A5 (10), J402.A6 (12), J402.A7 (14), J402.A8 (16), J402.A9 (18), J402.A10 (20), J402.A11 (22), J402.A12 (24), J402.A13 (26), J402.A14 (28), J402.A15 (30), J402.A16 (32), J402.A17 (34), J402.A20 (40), J402.B2 (3), J402.B4 (7), J402.B8 (15), J402.B18 (35), J402.B19 (37), J403.A2 (4), J403.A4 (8), J403.A5 (10), J403.A6 (12), J403.A7 (14), J403.A8 (16), J403.A9 (18), J403.A10 (20), J403.A11 (22), J403.A12 (24), J403.A13 (26), J403.A14 (28), J403.A15 (30), J403.A16 (32), J403.A17 (34), J403.A20 (40), J403.B2 (3), J403.B4 (7), J403.B8 (15), J403.B18 (35), J403.B19 (37), J404.A1 (2), J404.A4 (8), J404.A8 (16), J404.A12 (24), J404.A13 (26), J404.A14 (28), J404.A15 (30), J404.A17 (34), J404.A19 (38), J404.B3 (5), J404.B4 (7), J404.B8 (15), J404.B12 (23), J404.B17 (33), J405.A2 (4), J405.A4 (8), J405.A5 (10), J405.A6 (12), J405.A7 (14), J405.A8 (16), J405.A9 (18), J405.A10 (20), J405.A11 (22), J405.A12 (24), J405.A13 (26), J405.A14 (28), J405.A15 (30), J405.A16 (32), J405.A17 (34), J405.A20 (40), J405.B2 (3), J405.B4 (7), J405.B8 (15), J405.B18 (35), J405.B19 (37), J406.A2 (4), J406.A4 (8), J406.A5 (10), J406.A6 (12), J406.A7 (14), J406.A8 (16), J406.A9 (18), J406.A10 (20), J406.A11 (22), J406.A12 (24), J406.A13 (26), J406.A14 (28), J406.A15 (30), J406.A16 (32), J406.A17 (34), J406.A20 (40), J406.B2 (3), J406.B4 (7), J406.B8 (15), J406.B18 (35), J406.B19 (37), J407.A2 (4), J407.A4 (8), J407.A5 (10), J407.A6 (12), J407.A7 (14), J407.A8 (16), J407.A9 (18), J407.A10 (20), J407.A11 (22), J407.A12 (24), J407.A13 (26), J407.A14 (28), J407.A15 (30), J407.A16 (32), J407.A17 (34), J407.A20 (40), J407.B2 (3), J407.B4 (7), J407.B8 (15), J407.B18 (35), J407.B19 (37), J408.2, J408.4, J408.6, J408.8, J408.10, TP406.P$1; also elsewhere on the board
unnamed: J401.B9 (17), TP401.P$1
RES1: J402.B9 (17), J408.7
RES2: J403.B9 (17), J408.9
RES3: J405.B9 (17), J408.1
RES4: J406.B9 (17), J408.3
RES5: J407.B9 (17), J408.5
V5P1_DET2: J401.A1 (2), J401.A3 (6), J401.B1 (1), J401.B3 (5), J402.A1 (2), J402.A3 (6), J402.B1 (1), J402.B3 (5), J403.A1 (2), J403.A3 (6), J403.B1 (1), J403.B3 (5), J404.A18 (36), J404.A20 (40), J404.B18 (35), J404.B19 (37), J404.B20 (39), J405.A1 (2), J405.A3 (6), J405.B1 (1), J405.B3 (5), J406.A1 (2), J406.A3 (6), J406.B1 (1), J406.B3 (5), J407.A1 (2), J407.A3 (6), J407.B1 (1), J407.B3 (5), TP402.P$1
V9P0_DET2: J401.A18 (36), J402.A18 (36), J403.A18 (36), J404.A3 (6), J405.A18 (36), J406.A18 (36), J407.A18 (36), TP403.P$1
VN3P4_DET2: J401.A19 (38), J402.A19 (38), J403.A19 (38), J404.A2 (4), J405.A19 (38), J406.A19 (38), J407.A19 (38), TP404.P$1
VN22_DET2: J401.B20 (39), J402.B20 (39), J403.B20 (39), J404.B1 (1), J404.B2 (3), J405.B20 (39), J406.B20 (39), J407.B20 (39), TP405.P$1

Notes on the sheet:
Six Layer Detector Adapter Backplane
from Detector Adapter Board
from Control Board
GPIO00
GPIO01
GPIO02
GPIO03
GPIO04
GPIO05
GPIO06
UART_DETB_TO_FPGA
UART_FPGA_TO_DETB
DETB_SELECT
DETB_TRIGGER
DETB_END_CYC
DETB_STATUS_SELECT
DETB_RESERVED
DETB_RUN
debugging / testing
UART_DETB_TO_FPGA0
DETB_SELECT0
DETB_SELECT1
DETB_SELECT2
DETB_SELECT5
DETB_SELECT3
DETB_SELECT4
UART_DETB_TO_FPGA1
UART_DETB_TO_FPGA2
UART_DETB_TO_FPGA4
UART_DETB_TO_FPGA5
UART_DETB_TO_FPGA3
Alt. Name (FPGA)
Alt. Name (RP2040)

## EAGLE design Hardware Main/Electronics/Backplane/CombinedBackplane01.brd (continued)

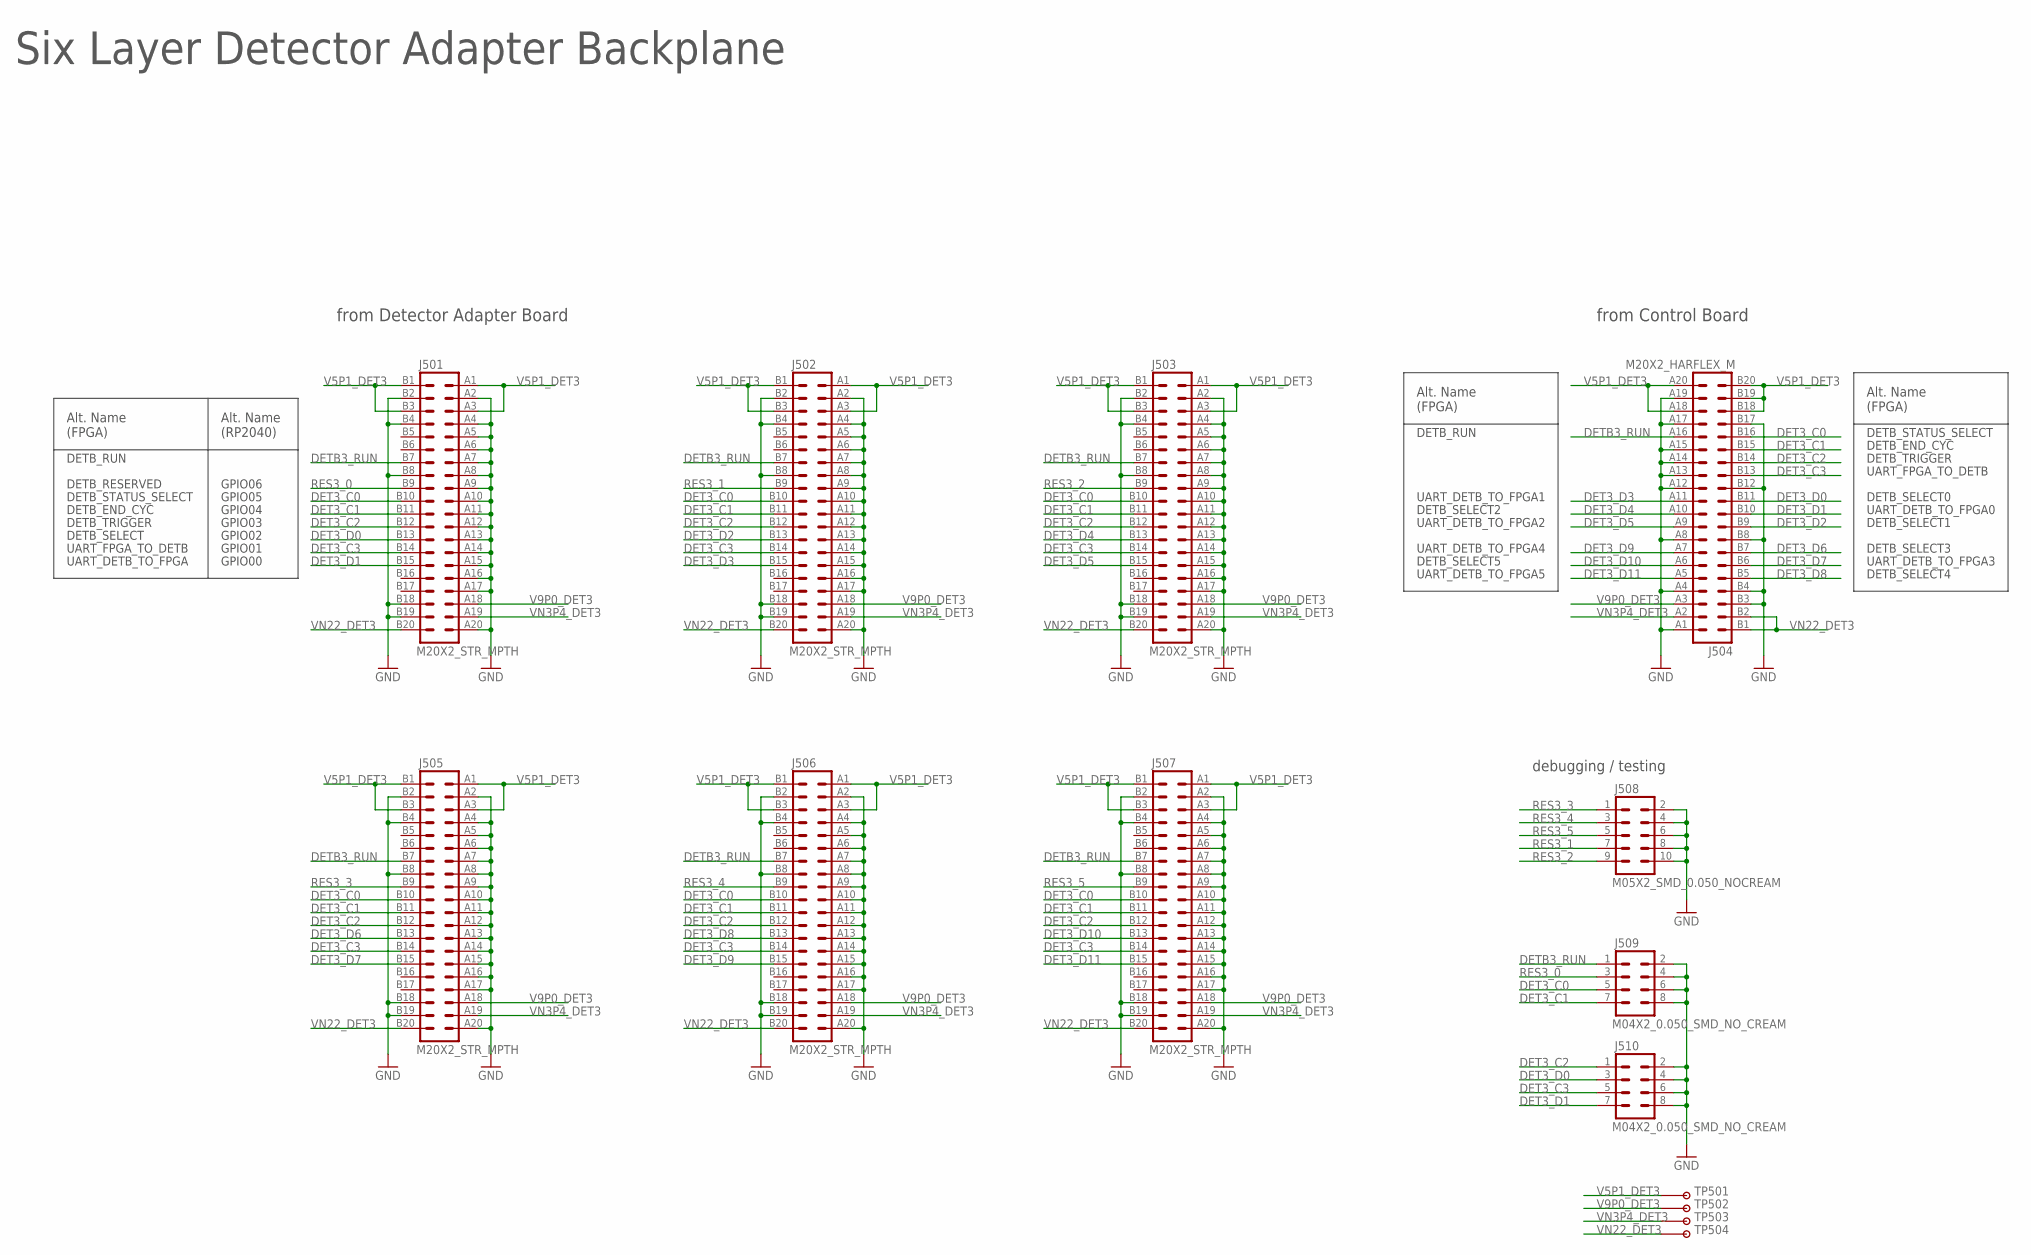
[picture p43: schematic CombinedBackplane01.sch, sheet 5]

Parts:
J501, J502, J503, J505, J506, J507: M20X2_STR_MPTH; M20X2_HARFLEX_F_STR_MPTH
J504: M20X2_HARFLEX_M
J508: M05X2_SMD_0.050_NOCREAM; M05X2_0.050_SMD_NO_CREAM
J509, J510: M04X2_0.050_SMD_NO_CREAM
TP501, TP502, TP503, TP504: TESTPOINT_ROUND; TESTPAD_ROUND

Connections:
DET3_C0: J501.B10 (19), J502.B10 (19), J503.B10 (19), J504.B16 (31), J505.B10 (19), J506.B10 (19), J507.B10 (19), J509.5
DET3_C1: J501.B11 (21), J502.B11 (21), J503.B11 (21), J504.B15 (29), J505.B11 (21), J506.B11 (21), J507.B11 (21), J509.7
DET3_C2: J501.B12 (23), J502.B12 (23), J503.B12 (23), J504.B14 (27), J505.B12 (23), J506.B12 (23), J507.B12 (23), J510.1
DET3_C3: J501.B14 (27), J502.B14 (27), J503.B14 (27), J504.B13 (25), J505.B14 (27), J506.B14 (27), J507.B14 (27), J510.5
DET3_D0: J501.B13 (25), J504.B11 (21), J510.3
DET3_D1: J501.B15 (29), J504.B10 (19), J510.7
DET3_D2: J502.B13 (25), J504.B9 (17)
DET3_D3: J502.B15 (29), J504.A11 (22)
DET3_D4: J503.B13 (25), J504.A10 (20)
DET3_D5: J503.B15 (29), J504.A9 (18)
DET3_D6: J504.B7 (13), J505.B13 (25)
DET3_D7: J504.B6 (11), J505.B15 (29)
DET3_D8: J504.B5 (9), J506.B13 (25)
DET3_D9: J504.A7 (14), J506.B15 (29)
DET3_D10: J504.A6 (12), J507.B13 (25)
DET3_D11: J504.A5 (10), J507.B15 (29)
DETB3_RUN: J501.B7 (13), J502.B7 (13), J503.B7 (13), J504.A16 (32), J505.B7 (13), J506.B7 (13), J507.B7 (13), J509.1
GND: J501.A2 (4), J501.A4 (8), J501.A5 (10), J501.A6 (12), J501.A7 (14), J501.A8 (16), J501.A9 (18), J501.A10 (20), J501.A11 (22), J501.A12 (24), J501.A13 (26), J501.A14 (28), J501.A15 (30), J501.A16 (32), J501.A17 (34), J501.A20 (40), J501.B2 (3), J501.B4 (7), J501.B8 (15), J501.B18 (35), J501.B19 (37), J502.A2 (4), J502.A4 (8), J502.A5 (10), J502.A6 (12), J502.A7 (14), J502.A8 (16), J502.A9 (18), J502.A10 (20), J502.A11 (22), J502.A12 (24), J502.A13 (26), J502.A14 (28), J502.A15 (30), J502.A16 (32), J502.A17 (34), J502.A20 (40), J502.B2 (3), J502.B4 (7), J502.B8 (15), J502.B18 (35), J502.B19 (37), J503.A2 (4), J503.A4 (8), J503.A5 (10), J503.A6 (12), J503.A7 (14), J503.A8 (16), J503.A9 (18), J503.A10 (20), J503.A11 (22), J503.A12 (24), J503.A13 (26), J503.A14 (28), J503.A15 (30), J503.A16 (32), J503.A17 (34), J503.A20 (40), J503.B2 (3), J503.B4 (7), J503.B8 (15), J503.B18 (35), J503.B19 (37), J504.A1 (2), J504.A4 (8), J504.A8 (16), J504.A12 (24), J504.A13 (26), J504.A14 (28), J504.A15 (30), J504.A17 (34), J504.A19 (38), J504.B3 (5), J504.B4 (7), J504.B8 (15), J504.B12 (23), J504.B17 (33), J505.A2 (4), J505.A4 (8), J505.A5 (10), J505.A6 (12), J505.A7 (14), J505.A8 (16), J505.A9 (18), J505.A10 (20), J505.A11 (22), J505.A12 (24), J505.A13 (26), J505.A14 (28), J505.A15 (30), J505.A16 (32), J505.A17 (34), J505.A20 (40), J505.B2 (3), J505.B4 (7), J505.B8 (15), J505.B18 (35), J505.B19 (37), J506.A2 (4), J506.A4 (8), J506.A5 (10), J506.A6 (12), J506.A7 (14), J506.A8 (16), J506.A9 (18), J506.A10 (20), J506.A11 (22), J506.A12 (24), J506.A13 (26), J506.A14 (28), J506.A15 (30), J506.A16 (32), J506.A17 (34), J506.A20 (40), J506.B2 (3), J506.B4 (7), J506.B8 (15), J506.B18 (35), J506.B19 (37), J507.A2 (4), J507.A4 (8), J507.A5 (10), J507.A6 (12), J507.A7 (14), J507.A8 (16), J507.A9 (18), J507.A10 (20), J507.A11 (22), J507.A12 (24), J507.A13 (26), J507.A14 (28), J507.A15 (30), J507.A16 (32), J507.A17 (34), J507.A20 (40), J507.B2 (3), J507.B4 (7), J507.B8 (15), J507.B18 (35), J507.B19 (37), J508.2, J508.4, J508.6, J508.8, J508.10, J509.2, J509.4, J509.6, J509.8, J510.2, J510.4, J510.6, J510.8; also elsewhere on the board
RES3_0: J501.B9 (17), J509.3
RES3_1: J502.B9 (17), J508.7
RES3_2: J503.B9 (17), J508.9
RES3_3: J505.B9 (17), J508.1
RES3_4: J506.B9 (17), J508.3
RES3_5: J507.B9 (17), J508.5
V5P1_DET3: J501.A1 (2), J501.A3 (6), J501.B1 (1), J501.B3 (5), J502.A1 (2), J502.A3 (6), J502.B1 (1), J502.B3 (5), J503.A1 (2), J503.A3 (6), J503.B1 (1), J503.B3 (5), J504.A18 (36), J504.A20 (40), J504.B18 (35), J504.B19 (37), J504.B20 (39), J505.A1 (2), J505.A3 (6), J505.B1 (1), J505.B3 (5), J506.A1 (2), J506.A3 (6), J506.B1 (1), J506.B3 (5), J507.A1 (2), J507.A3 (6), J507.B1 (1), J507.B3 (5), TP501.P$1
V9P0_DET3: J501.A18 (36), J502.A18 (36), J503.A18 (36), J504.A3 (6), J505.A18 (36), J506.A18 (36), J507.A18 (36), TP502.P$1
VN3P4_DET3: J501.A19 (38), J502.A19 (38), J503.A19 (38), J504.A2 (4), J505.A19 (38), J506.A19 (38), J507.A19 (38), TP503.P$1
VN22_DET3: J501.B20 (39), J502.B20 (39), J503.B20 (39), J504.B1 (1), J504.B2 (3), J505.B20 (39), J506.B20 (39), J507.B20 (39), TP504.P$1

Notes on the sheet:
Six Layer Detector Adapter Backplane
from Detector Adapter Board
from Control Board
GPIO00
GPIO01
GPIO02
GPIO03
GPIO04
GPIO05
GPIO06
UART_DETB_TO_FPGA
UART_FPGA_TO_DETB
DETB_SELECT
DETB_TRIGGER
DETB_END_CYC
DETB_STATUS_SELECT
DETB_RESERVED
DETB_RUN
debugging / testing
UART_DETB_TO_FPGA0
DETB_SELECT0
DETB_SELECT1
DETB_SELECT2
DETB_SELECT5
DETB_SELECT3
DETB_SELECT4
UART_DETB_TO_FPGA1
UART_DETB_TO_FPGA2
UART_DETB_TO_FPGA4
UART_DETB_TO_FPGA5
UART_DETB_TO_FPGA3
Alt. Name (FPGA)
Alt. Name (RP2040)

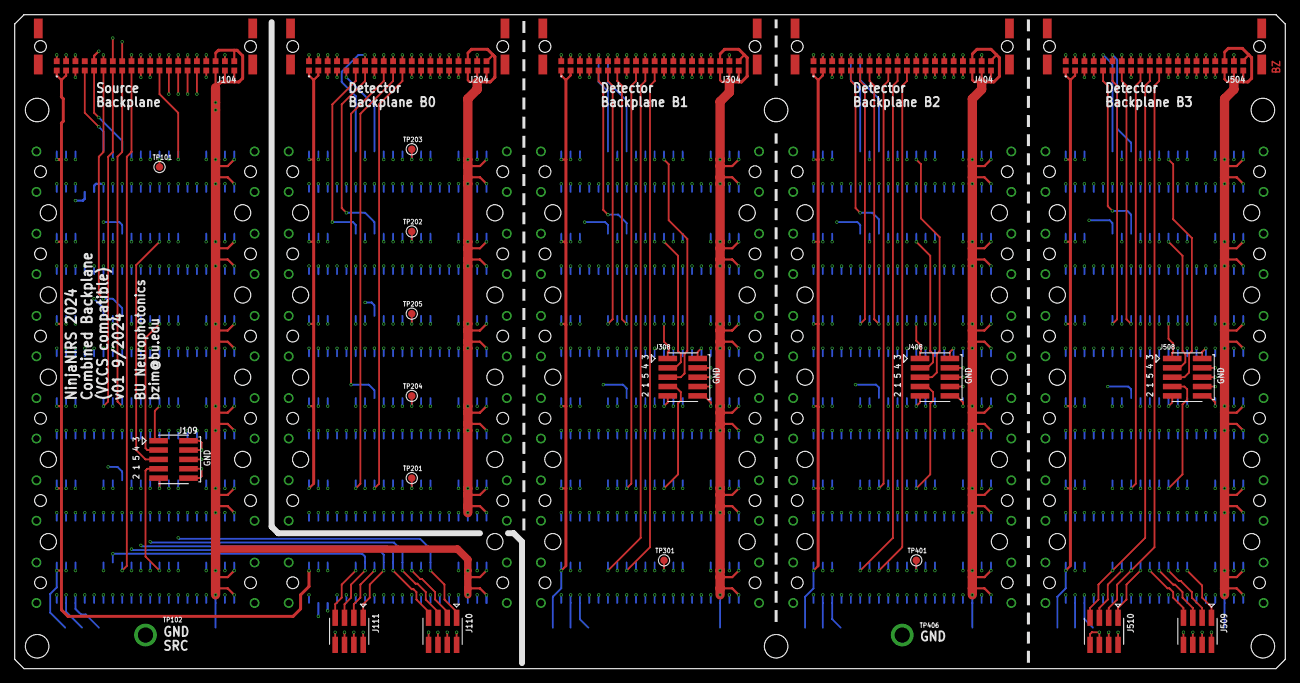
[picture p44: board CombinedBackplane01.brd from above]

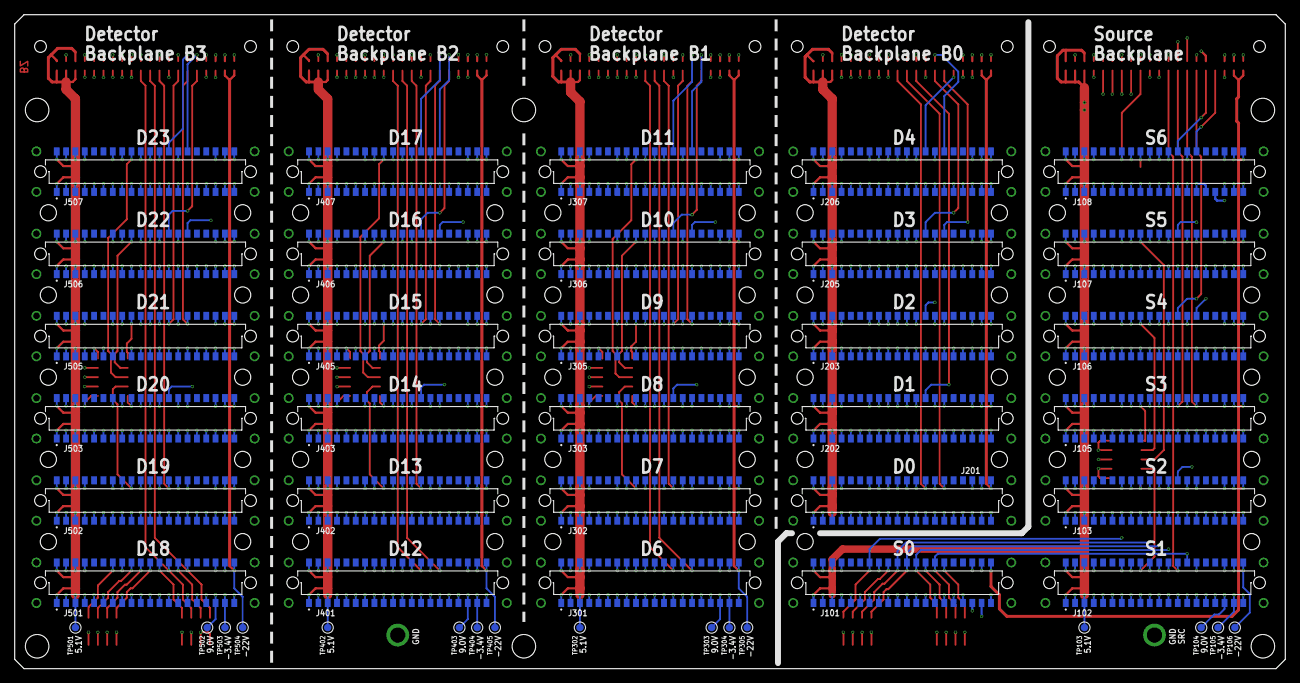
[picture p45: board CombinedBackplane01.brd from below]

Board: 4 copper layers, 172.7 x 88.9 mm, 69 parts (46 on the bottom side), 137 nets.

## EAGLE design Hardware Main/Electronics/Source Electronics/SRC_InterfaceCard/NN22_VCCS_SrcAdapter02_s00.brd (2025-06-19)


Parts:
C1, C2: 0.1u; 0402-CAP
D1, D2, D3, D4, D5, D6, D7, D8: BAV70W; SOT323
J1: M04X2_0.050_SMD_NO_CREAM
J2: M13X2_0.050_SHF
Q1, Q2, Q3, Q4, Q5, Q6, Q7, Q8: MOSFET-DUAL-N-UDFN8; UDFN8
R1: 0; 1206
TP1, TP2: TESTPOINT_ROUND; TESTPAD_ROUND
TP14: TESTPOINTPADSMALL; TESTPAD_SMALL
U1, U2: 74HC238_TSSOP; TSSOP16

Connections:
DUMMY_EN: J1.2; also elsewhere on the board
GND: C1.2, C2.2, J1.1, J1.3, J1.5, J1.7, J2.25, U1.8 (GND), U2.4 (G2A#), U2.8 (GND); also elsewhere on the board
LED_0A: D8.1 (A1), J2.1, Q4.6 (D), Q4.P1 (D), TP1.P$1
LED_0B: D4.1 (A1), J2.4, Q4.3 (D), Q4.P2 (D)
LED_1A: D4.2 (A2), J2.6, Q8.6 (D), Q8.P1 (D)
LED_1B: D8.2 (A2), J2.5, Q8.3 (D), Q8.P2 (D)
LED_2A: D7.1 (A1), J2.7, Q3.6 (D), Q3.P1 (D)
LED_2B: D3.1 (A1), J2.10, Q3.3 (D), Q3.P2 (D)
LED_3A: D3.2 (A2), J2.12, Q7.6 (D), Q7.P1 (D)
LED_3B: D7.2 (A2), J2.11, Q7.3 (D), Q7.P2 (D)
LED_4A: D6.1 (A1), J2.13, Q2.6 (D), Q2.P1 (D)
LED_4B: D2.1 (A1), J2.16, Q2.3 (D), Q2.P2 (D)
LED_5A: D2.2 (A2), J2.18, Q6.6 (D), Q6.P1 (D)
LED_5B: D6.2 (A2), J2.17, Q6.3 (D), Q6.P2 (D)
LED_6A: D5.1 (A1), J2.19, Q1.6 (D), Q1.P1 (D)
LED_6B: D1.1 (A1), J2.22, Q1.3 (D), Q1.P2 (D)
LED_7A: D1.2 (A2), J2.24, Q5.6 (D), Q5.P1 (D)
LED_7B: D5.2 (A2), J2.23, Q5.3 (D), Q5.P2 (D), TP2.P$1
LED_A: D1.3 (C), D2.3 (C), D3.3 (C), D4.3 (C), D5.3 (C), D6.3 (C), D7.3 (C), D8.3 (C), J2.2, J2.3, J2.8, J2.9, J2.14, J2.15, J2.20, J2.21, J2.26, R1.1
LED_AD[0]: U1.1 (A), U2.1 (A); also elsewhere on the board
LED_AD[1]: U1.2 (B), U2.2 (B); also elsewhere on the board
LED_AD[2]: J1.8, U1.3 (C), U2.3 (C); also elsewhere on the board
LED_AD[3]: J1.6, U1.4 (G2A#), U2.6 (G1); also elsewhere on the board
LED_COM: Q1.1 (S), Q1.4 (S), Q2.1 (S), Q2.4 (S), Q3.1 (S), Q3.4 (S), Q4.1 (S), Q4.4 (S), Q5.1 (S), Q5.4 (S), Q6.1 (S), Q6.4 (S), Q7.1 (S), Q7.4 (S), Q8.1 (S), Q8.4 (S); also elsewhere on the board
LED_ENN: J1.4, U1.5 (G2B#), U2.5 (G2B#); also elsewhere on the board
unnamed: Q4.5 (G), U1.14 (Y1)
unnamed: Q3.5 (G), TP14.P$1, U1.10 (Y5)
unnamed: Q8.5 (G), U1.12 (Y3)
unnamed: Q8.2 (G), U1.13 (Y2)
unnamed: Q7.5 (G), U1.7 (Y7)
unnamed: Q7.2 (G), U1.9 (Y6)
unnamed: Q2.5 (G), U2.14 (Y1)
unnamed: Q6.5 (G), U2.12 (Y3)
unnamed: Q6.2 (G), U2.13 (Y2)
unnamed: Q1.5 (G), U2.10 (Y5)
unnamed: Q5.5 (G), U2.7 (Y7)
unnamed: Q5.2 (G), U2.9 (Y6)
unnamed: Q4.2 (G), U1.15 (Y0)
unnamed: Q3.2 (G), U1.11 (Y4)
unnamed: Q2.2 (G), U2.15 (Y0)
unnamed: Q1.2 (G), U2.11 (Y4)
V4P0: C1.1, C2.1, U1.6 (G1), U1.16 (VCC), U2.16 (VCC); also elsewhere on the board
VLED: R1.2; also elsewhere on the board

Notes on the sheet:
to Optode Bundle
LED Select Switches
LED Select Debug


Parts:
C3, C5, C7, C8, C10: 0.1u; 0402-CAP
C4, C11: 10n; 0402-CAP
C6, C9: 100p; 0402-CAP
C12: DNP; 0603-CAP
J3: M04X2_0.050_SMD_NO_CREAM
J4: U.FL
Q9, Q10: MOSFET-DUAL-N-UDFN8; UDFN8
R2, R4, R5, R32: 10k; 0402-RES
R3: 24k; 0402-RES
R6, R10: 100; 0402-RES
R7: 1.2k; 0402-RES
R8: 8.2; R2512
R9: 10; 0603-RES
R11: 1; 0603-RES
R12: 150; 0603-RES
R13: DNP; 0603-RES
TP3, TP4, TP15: TESTPOINT_ROUND; TESTPAD_ROUND
U3: AD5683R_MSOP; MSOP10
U4: OPA392_SOT23; SOT23-5

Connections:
DAC_CSN: J3.2, U3.7 (SYNC#); also elsewhere on the board
DAC_LDACN: J3.8, U3.4 (LDAC#); also elsewhere on the board
DAC_MOSI: J3.6, U3.8 (SDIN); also elsewhere on the board
DAC_RESETN: U3.3 (RESET#); also elsewhere on the board
DAC_SCLK: J3.4, U3.6 (SCLK); also elsewhere on the board
DUMMY_EN: Q10.1 (S); also elsewhere on the board
GND: C3.2, C4.2, C5.2, C6.2, C7.2, C8.2, C10.2, C11.2, C12.2, J3.1, J3.3, J3.5, J3.7, J4.P$1 (GND), J4.P$2 (GND), Q9.1 (S), Q9.2 (G), Q9.6 (D), Q9.P1 (D), R3.1, R8.1, U3.5 (GND); also elsewhere on the board
LED_COM: Q9.3 (D), Q9.P2 (D), Q10.4 (S), R5.2, R9.2, R11.2, R13.2, TP15.P$1; also elsewhere on the board
LED_COM_SENSE: R5.1; also elsewhere on the board
LED_CURR_SENSE: R4.1; also elsewhere on the board
unnamed: Q9.5 (G), R6.2
unnamed: R2.1, U3.10 (VOUT)
unnamed: Q10.3 (D), Q10.P2 (D), R12.1
unnamed: C6.1, R2.2, R3.2, TP3.P$1, U4.3 (+IN)
unnamed: C9.1, R6.1, U4.1 (OUT)
unnamed: Q10.5 (G), Q10.6 (D), Q10.P1 (D), R32.1
unnamed: Q9.4 (S), R4.2, R7.2, R8.2, R10.1, TP4.P$1
unnamed: C9.2, R7.1, U4.4 (-IN)
unnamed: C4.1, U3.9 (VREF)
unnamed: J4.P$3 (SIGNAL), R10.2
unnamed: C11.1, R11.1
unnamed: C10.1, R9.1
unnamed: C12.1, R13.1
V3P3: C5.1, Q10.2 (G), U3.2 (VLOGIC); also elsewhere on the board
V4P0: C3.1, C7.1, R32.2, U3.1 (VDD), U4.5 (V+); also elsewhere on the board
VLED: R12.2; also elsewhere on the board
VN1P2: C8.1, U4.2 (V-); also elsewhere on the board

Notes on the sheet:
DAC SPI Debug
DAC / VCCS
Current Monitor (Debug)


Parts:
C13, C14, C15, C16: 100p; 0402-CAP
C17: 0.1u; 0402-CAP
C18, C19: 27p; 0402-CAP
D9: BAV70W; SOT323
J5: M20X2_HARFLEX_M
J6: M03X1_JST_SH_RA; M03X1_JST_SH_SM_RA
J7: USB-MICRO
LED1, LED2: LED0603; LED-0603
R14, R15, R20, R23: 1.2k; 0402-RES
R16, R19: 10k; 0402-RES
R17, R18: 28k; 0402-RES
R21, R22: 100k; 0402-RES
R24, R25, R33, R34: 27; 0402-RES
S1: SWITCH-MOMENTARY-2SMD-3; TACTILE_SWITCH_SMD-3
TP5, TP6: TESTPOINTPADSMALL; TESTPAD_SMALL
U5: RP2040; QFN-56_EP
U6: W25Q_USON; USON8L-2X3MM
X1: CRYSTAL-3.2-2.5

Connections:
BOOTSEL: J5.B17 (33), R20.1, S1.4 (2)
DAC_CSN: U5.32 (GPIO21); also elsewhere on the board
DAC_LDACN: U5.29 (GPIO18); also elsewhere on the board
DAC_MOSI: U5.35 (GPIO23); also elsewhere on the board
DAC_RESETN: U5.36 (GPIO24); also elsewhere on the board
DAC_SCLK: U5.34 (GPIO22); also elsewhere on the board
DUMMY_EN: U5.28 (GPIO17); also elsewhere on the board
GND: C13.2, C14.2, C15.2, C16.2, C17.2, C18.2, C19.2, D9.2 (A2), J5.A2 (4), J5.A4 (8), J5.A5 (10), J5.A6 (12), J5.A7 (14), J5.A8 (16), J5.A9 (18), J5.A10 (20), J5.A11 (22), J5.A12 (24), J5.A13 (26), J5.A14 (28), J5.A15 (30), J5.A16 (32), J5.A17 (34), J5.A20 (40), J5.B2 (3), J5.B4 (7), J5.B8 (15), J5.B18 (35), J5.B19 (37), J6.2, J7.5, J7.SH1, J7.SH2, J7.SH3, J7.SH4, J7.SH5, J7.SH6, LED1.C, LED2.C, R19.1, S1.1, U5.19 (TESTEN), U6.4 (GND), X1.2 (GND), X1.4 (GND); also elsewhere on the board
GPIO00: J5.B15 (29), U5.2 (GPIO00)
GPIO01: J5.B14 (27), U5.3 (GPIO01)
GPIO02: J5.B13 (25), U5.4 (GPIO02)
GPIO03: J5.B12 (23), U5.5 (GPIO03)
GPIO04: J5.B11 (21), U5.6 (GPIO04)
GPIO05: J5.B10 (19), U5.7 (GPIO05)
GPIO06: J5.B9 (17), U5.8 (GPIO06)
LED0: R14.2, U5.11 (GPIO08)
LED1: R15.2, U5.9 (GPIO07)
LED_AD[0]: U5.15 (GPIO12); also elsewhere on the board
LED_AD[1]: U5.16 (GPIO13); also elsewhere on the board
LED_AD[2]: U5.17 (GPIO14); also elsewhere on the board
LED_AD[3]: U5.18 (GPIO15); also elsewhere on the board
LED_COM_SENSE: C13.1, U5.41 (GPIO29/ADC3); also elsewhere on the board
LED_CURR_SENSE: C14.1, U5.38 (GPIO26/ADC0); also elsewhere on the board
LED_ENN: U5.27 (GPIO16); also elsewhere on the board
unnamed: C19.1, U5.20 (XIN), X1.3 (C2)
unnamed: C18.1, R23.2, X1.1 (C1)
unnamed: R23.1, U5.21 (XOUT)
unnamed: R24.1, U5.47 (USB_DP)
unnamed: R25.1, U5.46 (USB_DN)
unnamed: R34.1, U5.25 (SWDIO)
unnamed: R33.1, U5.24 (SWCLK)
unnamed: J7.2, R25.2
unnamed: J7.3, R24.2
unnamed: LED1.A, R14.1
unnamed: LED2.A, R15.1
QSPI_SCLK: U5.52 (QSPI_SCLK), U6.6 (CLK)
QSPI_SD0: U5.53 (QSPI_SD0), U6.5 (DI/IO[0])
QSPI_SD1: U5.55 (QSPI_SD1), U6.2 (DO/IO[1])
QSPI_SD2: U5.54 (QSPI_SD2), U6.3 (#WP/IO[2])
QSPI_SD3: U5.51 (QSPI_SD3), U6.7 (#HOLD/IO[3])
QSPI_SS_N: R20.2, R22.1, U5.56 (QSPI_SS_N), U6.1 (/CS)
RUN: J5.B7 (13), R21.1, U5.26 (RUN)
SPARE0: TP5.P$1, U5.30 (GPIO19)
SPARE1: TP6.P$1, U5.31 (GPIO20)
SWCLK: J5.B6 (11), J6.1, R33.2
SWDIO: J5.B5 (9), J6.3, R34.2
V3P3: C17.1, J5.B16 (31), R16.2, R21.2, R22.2, U6.8 (VCC); also elsewhere on the board
VBUS: J7.1; also elsewhere on the board
VIN: J5.A1 (2), J5.A3 (6), J5.B1 (1), J5.B3 (5); also elsewhere on the board
VIN_F: R18.2; also elsewhere on the board
VIN_SENSE: C16.1, R18.1, R19.2, U5.39 (GPIO27/ADC1)
VLED_EN: U5.13 (GPIO10); also elsewhere on the board
VN3P0: J5.A19 (38), R17.1; also elsewhere on the board
VN3P0_SENSE: C15.1, D9.3 (C), R16.1, R17.2, U5.40 (GPIO28/ADC2)

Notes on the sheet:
BOOTSEL (force USB boot)
RP2040 / Backplane
to Backplane
CTS-Frequency Controls 403I35D12M00000
UART_SRCB_TO_FPGA
UART_FPGA_TO_SRCB
SRCB_SELECT
SRCB_STEP
SRCB_LED_EN
SRCB_SPARE
SRCB_RESERVED
SRCB_RUN
Alt. Name (FPGA)
red
green
Alt. Name (Firmware)
UART_TX_PIN
UART_RX_PIN
BOARD_SELECTN_PIN
STEP_PIN
LED_EN_IN_PIN
STATUS_SELECT_PIN
RESERVED_PIN


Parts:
C20: 150u; 2917-CAP
C21, C23, C25, C30, C33, C34, C36, C38, C39, C41, C42, C43: 0.1u; 0402-CAP
C22, C24, C44, C45, C46: 10u; 0603-CAP
C26, C27, C28, C29, C31, C35, C37, C40: 4.7u; 0402-CAP
C32: DNP; 0402-CAP
D10, D11: BAV70W; SOT323
F1: 0ZCH0035FF2G; 1210-FUSE
FID1, FID2, FID3, FID4, FID5, FID6, FID7, FID8: FIDUCIALUFIDUCIAL; MICRO-FIDUCIAL
R26: 100k; 0402-RES
R27, R28: 10k; 0402-RES
R29: 24k; 0402-RES
R30: 28k; 0402-RES
R31: 27; 0402-RES
TP7, TP8, TP9, TP10, TP11: TESTPOINT_ROUND; TESTPAD_ROUND
TP12: TESTPOINTPADSMALL; TESTPAD_SMALL
TP13: TESTPOINT1X01; 1X01
U5: RP2040; QFN-56_EP
U7: ADP7182_WSON; WSON6
U8: MCP1755_DFN; DFN8_2X3MM
U9, U10: LDL212_DFN6_3X3; DFN6_3X3MM

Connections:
GND: C20.N, C21.2, C22.2, C23.2, C24.1, C25.2, C26.2, C27.1, C28.2, C29.2, C30.2, C31.2, C32.2, C33.2, C34.2, C35.2, C36.2, C37.2, C38.2, C39.2, C40.2, C41.2, C42.2, C43.2, C44.2, C45.2, C46.2, R26.1, R27.1, R28.1, TP13.1, U5.PAD (GND), U7.5 (GND), U8.4 (GND), U8.P (GND), U9.1 (GND), U9.PAD (GND), U10.1 (GND), U10.PAD (GND); also elsewhere on the board
unnamed: R27.2, R29.1, U9.2 (ADJ/SENSE)
unnamed: R28.2, R30.1, U10.2 (ADJ/SENSE)
unnamed: C40.1, R31.2, U5.43 (ADC_VDD)
V1P1: C33.1, C34.1, C35.1, TP12.P$1, U5.23 (DVDD), U5.45 (VREG_VOUT), U5.50 (DVDD)
V3P3: C26.1, C28.1, C36.1, C37.1, C38.1, C39.1, C41.1, C42.1, C43.1, R31.1, TP8.P$1, U5.1 (IOVDD), U5.10 (IOVDD), U5.22 (IOVDD), U5.33 (IOVDD), U5.42 (IOVDD), U5.44 (VREG_VIN), U5.48 (USB_VDD), U5.49 (IOVDD), U8.1 (OUT); also elsewhere on the board
V4P0: C29.1, C31.1, R29.2, TP10.P$1, U9.3 (VOUT); also elsewhere on the board
VBUS: D10.1 (A1), D10.2 (A2); also elsewhere on the board
VIN: D11.1 (A1), D11.2 (A2), F1.2; also elsewhere on the board
VIN_F: C20.P, C21.1, C23.1, C44.1, C45.1, F1.1, U9.4 (VIN), U9.6 (EN), U10.4 (VIN); also elsewhere on the board
VIN_MCU: C22.1, C25.1, D10.3 (C), D11.3 (C), TP7.P$1, U8.5 (/SHDN), U8.8 (IN)
VLED: C30.1, C32.1, C46.1, R30.2, TP11.P$1, U10.3 (VOUT); also elsewhere on the board
VLED_EN: R26.2, U10.6 (EN); also elsewhere on the board
VN1P2: C27.2, TP9.P$1, U7.1 (OUT), U7.2 (NC/ADJ); also elsewhere on the board
VN3P0: C24.2, U7.3 (EN), U7.6 (IN), U7.PAD (IN); also elsewhere on the board

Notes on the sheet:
Voltage Regulators
nominal: 1.18*(24/10+1) = 4.01V
nominal: 1.18*(28/10+1) = 4.48V

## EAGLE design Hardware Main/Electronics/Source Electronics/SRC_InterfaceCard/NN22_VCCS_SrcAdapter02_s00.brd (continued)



Board: 4 copper layers, 63.5 x 33.0 mm, 146 parts (60 on the bottom side), 109 nets.

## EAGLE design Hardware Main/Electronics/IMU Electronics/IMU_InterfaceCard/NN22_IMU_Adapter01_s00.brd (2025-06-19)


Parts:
C1, C24: 0.1u; 0402-CAP
D1, D2, D3, D4, D5, D6, D7, D8: D1213A-02SO; SOT23-6
J1: M13X2_0.050_SHF
J2: M20X2_HARFLEX_M
J3, J4: M04X2_0.050_SMD_NO_CREAM
LED1, LED2: LED0603; LED-0603
R1, R2, R10: 1.2k; 0402-RES
R3, R4, R5, R6, R7, R8, R9: 10; 0402-RES
R11, R13, R14: DNP; 0603-RES
R12, R15, R25, R26: 100k; 0402-RES
U1: RP2040; QFN-56_EP
U5: ISM330DHCX; LGA14-L

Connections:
BOOTSEL: J2.B17 (33); also elsewhere on the board
GND: C1.2, C24.2, D1.2 (VN), D2.2 (VN), D3.2 (VN), D4.2 (VN), D5.2 (VN), D6.2 (VN), D7.2 (VN), D8.2 (VN), J1.2, J1.4, J1.22, J1.24, J2.A2 (4), J2.A4 (8), J2.A5 (10), J2.A6 (12), J2.A7 (14), J2.A8 (16), J2.A9 (18), J2.A10 (20), J2.A11 (22), J2.A12 (24), J2.A13 (26), J2.A14 (28), J2.A15 (30), J2.A16 (32), J2.A17 (34), J2.A20 (40), J2.B2 (3), J2.B4 (7), J2.B8 (15), J2.B18 (35), J2.B19 (37), J3.1, J3.3, J3.5, J3.7, J4.1, J4.3, J4.5, J4.7, LED1.C, LED2.C, R15.1, U5.1 (SDO/SA0), U5.2 (SDX), U5.3 (SCX), U5.6 (GND), U5.7 (GND); also elsewhere on the board
GPIO00: J2.B15 (29), U1.2 (GPIO00)
GPIO01: J2.B14 (27), U1.3 (GPIO01)
GPIO02: J2.B13 (25), U1.4 (GPIO02)
GPIO03: J2.B12 (23), U1.5 (GPIO03)
GPIO04: J2.B11 (21), U1.6 (GPIO04)
GPIO05: J2.B10 (19), U1.7 (GPIO05)
GPIO06: J2.B9 (17), U1.8 (GPIO06)
IMU_SCL: J3.2, R25.1, U1.16 (GPIO13), U5.13 (SCL)
IMU_SDA: J3.4, R26.1, U1.15 (GPIO12), U5.14 (SDA)
IMU_SPARE: D6.3 (CH1), J1.19, R10.2
IMU_SPARE_PRE: R10.1, U1.40 (GPIO28/ADC2)
LED0: R2.2, U1.9 (GPIO07)
LED1: R1.2, U1.11 (GPIO08)
unnamed: J1.23, R11.2
unnamed: J1.25, R13.2
unnamed: J1.26, R14.2
unnamed: LED1.A, R1.1
unnamed: LED2.A, R2.1
RUN: J2.B7 (13); also elsewhere on the board
RX0: D7.4 (CH2), J1.14, J4.8, R7.1
RX0_PRE: R7.2, U1.36 (GPIO24)
RX1: D4.3 (CH1), J1.12, R5.1
RX1_PRE: R5.2, U1.27 (GPIO16)
RX2: D3.4 (CH2), J1.6, R3.1
RX2_PRE: J3.8, R3.2, U1.17 (GPIO14)
RX3: D1.4 (CH2), J1.9, R4.2
RX3_PRE: R4.1, U1.29 (GPIO18)
RX4: D5.4 (CH2), J1.17, R8.2
RX4_PRE: R8.1, U1.34 (GPIO22)
RX5: D8.4 (CH2), J1.18, J4.4, R9.1
RX5_PRE: R9.2, U1.38 (GPIO26/ADC0)
RX6: D2.4 (CH2), J1.13, R6.2
RX6_PRE: R6.1, U1.31 (GPIO20)
SWCLK: J2.B6 (11); also elsewhere on the board
SWDIO: J2.B5 (9); also elsewhere on the board
TX0: D7.3 (CH1), J1.16, J4.6, U1.37 (GPIO25)
TX1: D4.4 (CH2), J1.10, U1.28 (GPIO17)
TX2: D3.3 (CH1), J1.8, J3.6, U1.18 (GPIO15)
TX3: D1.3 (CH1), J1.7, U1.30 (GPIO19)
TX4: D5.3 (CH1), J1.15, U1.35 (GPIO23)
TX5: D8.3 (CH1), J1.20, J4.2, U1.39 (GPIO27/ADC1)
TX6: D2.3 (CH1), J1.11, U1.32 (GPIO21)
V3P3: C24.1, D1.6 (VP), D2.6 (VP), D3.6 (VP), D4.6 (VP), D5.6 (VP), D6.6 (VP), D7.6 (VP), D8.6 (VP), J2.B16 (31), R25.2, R26.2, U5.5 (VDDIO), U5.8 (VDD), U5.12 (CS); also elsewhere on the board
V9P0: J2.A18 (36), R11.1
VIMU: J1.1, J1.3, R12.2; also elsewhere on the board
VIMU_EN: U1.13 (GPIO10); also elsewhere on the board
VIMU_SENSE: C1.1, R12.1, R15.2, U1.41 (GPIO29/ADC3)
VIN_BP: J2.A1 (2), J2.A3 (6), J2.B1 (1), J2.B3 (5); also elsewhere on the board
VN3P0: J2.A19 (38), R13.1
VN22: J2.B20 (39), R14.1

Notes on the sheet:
RP2040 / Backplane
to Backplane
UART_DETB_TO_FPGA
UART_FPGA_TO_DETB
DETB_SELECT
DETB_TRIGGER
DETB_END_CYC
DETB_STATUS_SELECT
DETB_RESERVED
DETB_RUN
Alt. Name (FPGA)
to IMU Bundle
Debug
RX: from IMU Adapter to IMU Board TX: from IMU Board to IMU Adapter (IMU Board centric labeling)
On-board IMU


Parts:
C2, C7, C10: 10u; 0603-CAP
C3, C6, C8, C9, C16, C17, C18, C19, C20, C21, C22, C23: 0.1u; 0402-CAP
C4, C5, C13, C14, C15: 4.7u; 0402-CAP
C11, C12: 27p; 0402-CAP
D9, D10: BAV70W; SOT323
FID1, FID2, FID3, FID4, FID5, FID6, FID7, FID8: FIDUCIALUFIDUCIAL; MICRO-FIDUCIAL
J5: M03X1_JST_SH_RA; M03X1_JST_SH_SM_RA
J6: USB-MICRO
R16, R24: 1.2k; 0402-RES
R17, R18, R19: 100k; 0402-RES
R20: 82k; 0402-RES
R21, R22, R27, R28: 27; 0402-RES
R23: 33; 0402-RES
S1: SWITCH-MOMENTARY-2SMD-3; TACTILE_SWITCH_SMD-3
TP1, TP2, TP3: TESTPOINT_ROUND; TESTPAD_ROUND
TP4: TESTPOINTPADSMALL; TESTPAD_SMALL
TP5: TESTPOINT1X01; 1X01
U1: RP2040; QFN-56_EP
U2: MCP1755_DFN; DFN8_2X3MM
U3: W25Q_USON; USON8L-2X3MM
U4: AP2265X_SOT; SOT23-6
X1: CRYSTAL-3.2-2.5

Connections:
BOOTSEL: R16.1, S1.4 (2); also elsewhere on the board
GND: C2.2, C3.2, C4.2, C5.2, C6.2, C7.2, C8.2, C9.2, C10.2, C11.2, C12.2, C13.2, C14.2, C15.2, C16.2, C17.2, C18.2, C19.2, C20.2, C21.2, C22.2, C23.2, J5.2, J6.5, J6.SH1, J6.SH2, J6.SH3, J6.SH4, J6.SH5, J6.SH6, R19.1, R20.1, S1.1, TP5.1, U1.19 (TESTEN), U1.PAD (GND), U2.4 (GND), U2.P (GND), U3.4 (GND), U4.2 (GND), X1.2 (GND), X1.4 (GND); also elsewhere on the board
unnamed: R20.2, U4.5 (ILIM)
unnamed: C12.1, U1.20 (XIN), X1.3 (C2)
unnamed: C11.1, R24.2, X1.1 (C1)
unnamed: R24.1, U1.21 (XOUT)
unnamed: R21.1, U1.47 (USB_DP)
unnamed: R22.1, U1.46 (USB_DN)
unnamed: J6.2, R22.2
unnamed: J6.3, R21.2
unnamed: C15.1, R23.2, U1.43 (ADC_VDD)
QSPI_SCLK: U1.52 (QSPI_SCLK), U3.6 (CLK)
QSPI_SD0: U1.53 (QSPI_SD0), U3.5 (DI/IO[0])
QSPI_SD1: U1.55 (QSPI_SD1), U3.2 (DO/IO[1])
QSPI_SD2: U1.54 (QSPI_SD2), U3.3 (#WP/IO[2])
QSPI_SD3: U1.51 (QSPI_SD3), U3.7 (#HOLD/IO[3])
QSPI_SS_N: R16.2, R17.1, U1.56 (QSPI_SS_N), U3.1 (/CS)
RUN: R18.1, U1.26 (RUN); also elsewhere on the board
SWCLK: J5.1, R27.2; also elsewhere on the board
SWCLK_PRE: R27.1, U1.24 (SWCLK)
SWDIO: J5.3, R28.2; also elsewhere on the board
SWDIO_PRE: R28.1, U1.25 (SWDIO)
V1P1: C13.1, C16.1, C17.1, TP4.P$1, U1.23 (DVDD), U1.45 (VREG_VOUT), U1.50 (DVDD)
V3P3: C4.1, C5.1, C6.1, C14.1, C18.1, C19.1, C20.1, C21.1, C22.1, C23.1, R17.2, R18.2, R23.1, TP2.P$1, U1.1 (IOVDD), U1.10 (IOVDD), U1.22 (IOVDD), U1.33 (IOVDD), U1.42 (IOVDD), U1.44 (VREG_VIN), U1.48 (USB_VDD), U1.49 (IOVDD), U2.1 (OUT), U3.8 (VCC); also elsewhere on the board
VBUS: D9.1 (A1), D9.2 (A2), J6.1
VIMU: C9.1, C10.1, TP3.P$1, U4.6 (OUT); also elsewhere on the board
VIMU_EN: R19.2, U4.3 (EN); also elsewhere on the board
VIN: C2.1, C3.1, C7.1, C8.1, D9.3 (C), D10.3 (C), TP1.P$1, U2.5 (/SHDN), U2.8 (IN), U4.1 (IN)
VIN_BP: D10.1 (A1), D10.2 (A2); also elsewhere on the board

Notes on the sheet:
Voltage Regulators
BOOTSEL (force USB boot)
CTS-Frequency Controls 403I35D12M00000
30321/82^1.055 = 290mA



Board: 4 copper layers, 63.5 x 33.0 mm, 90 parts (27 on the bottom side), 72 nets.

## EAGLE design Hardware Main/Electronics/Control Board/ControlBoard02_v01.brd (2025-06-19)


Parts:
C101: 0.1u; 0402-CAP
D101: D1213A-02SO; SOT23-6
F101: 0ZCM0010FF2G; 0603-RES
J101: M20X2_PTH
J102, J103: M04X1_JST_SH_RA; M04X1_JST_SH_SM_RA
LED101: LTST-C191KRKT; LED-0603
LED102: LTST-C191KGKT; LED-0603
R101, R102, R103: 10k; 0402-RES
R104, R105: 470; 0402-RES
S101: SWITCH-MOMENTARY-2SMD-3; TACTILE_SWITCH_SMD-3

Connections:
GND: C101.2, D101.2 (VN), J101.1, J101.8, J101.12, J101.15, J101.22, J101.28, J101.31, J101.36, J102.1, J103.1, LED101.C, LED102.C, S101.1; also elsewhere on the board
unnamed: LED101.A, R104.1
unnamed: LED102.A, R105.1
RPI0_BUZZ: J101.7; also elsewhere on the board
RPI0_CE: J101.18; also elsewhere on the board
RPI0_GPIO5: J101.11; also elsewhere on the board
RPI0_GPIO6: J101.9; also elsewhere on the board
RPI0_GPIO7: J101.16; also elsewhere on the board
RPI0_GPIO12: J101.10; also elsewhere on the board
RPI0_GPIO16: J101.6; also elsewhere on the board
RPI0_GPIO18: J101.30; also elsewhere on the board
RPI0_GPIO19: J101.5; also elsewhere on the board
RPI0_GPIO20: J101.4; also elsewhere on the board
RPI0_GPIO21: J101.2; also elsewhere on the board
RPI0_GPIO22: J101.25; also elsewhere on the board
RPI0_GPIO24: J101.24; also elsewhere on the board
RPI0_GPIO25: J101.20; also elsewhere on the board
RPI0_GPIO26: J101.3; also elsewhere on the board
RPI0_GPIO27: J101.27, R103.1, S101.4 (2); also elsewhere on the board
RPI0_LED0: J101.29, R104.2
RPI0_LED1: J101.33, R105.2
RPI0_MISO: J101.19; also elsewhere on the board
RPI0_MOSI: J101.21; also elsewhere on the board
RPI0_RX0: J101.32; also elsewhere on the board
RPI0_SCL: D101.3 (CH1), J101.35, J102.4, J103.4, R102.1; also elsewhere on the board
RPI0_SCLK: J101.17; also elsewhere on the board
RPI0_SDA: D101.4 (CH2), J101.37, J102.3, J103.3, R101.1; also elsewhere on the board
RPI0_TX0: J101.34; also elsewhere on the board
RPI0_V3P3: F101.2, J101.23, J101.39, R103.2
V3P3_J102: C101.1, D101.6 (VP), F101.1, J102.2, J103.2, R101.2, R102.2
V5P1_RPI: J101.38, J101.40; also elsewhere on the board

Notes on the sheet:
GPIO15
GPIO14
RPI0_SWDIO
RPI0_SWCLK
GPIO8
GPIO11
GPIO9
GPIO10
GPIO2
GPIO3
GPIO13
RPi Zero 2 W
RPi Zero header mount Pi upside down
RPi0 Qwiic
GPIO23
Button
To spare connector J601 page 6
To FPGA U301 page 3
To RP2040 U201 page 2


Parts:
C201, C202, C203, C204, C207: 0.1u; 0402-CAP
C205, C206: 27p; 0402-CAP
D201, D202, D204: D1213A-02SO; SOT23-6
D203: DIODE_SOD523; SOD523
F201, F202, F203: 0ZCM0010FF2G; 0603-RES
J201, J202: M04X1_JST_SH_RA; M04X1_JST_SH_SM_RA
J203: USB-MICRO
J204, J205: M04X2_0.050_SMD_NO_CREAM
J206, J207: M03POLAR; MOLEX-1X3
LED201: LTST-C191KRKT; LED-0603
LED202, LED203: LTST-C191KGKT; LED-0603
Q201: MOSFET-NCHANNELSMD; SOT23-3
R201: 1k; 0402-RES
R202, R212, R214: DNP; 0402-RES
R203, R204, R207, R208, R210, R218: 10k; 0402-RES
R205, R217, R221: 100k; 0402-RES
R206: 47k; 0402-RES
R209, R211: 27; 0402-RES
R213: 1.2k; 0402-RES
R215, R216, R219, R220, R222: 470; 0402-RES
S201, S202: SWITCH-MOMENTARY-2SMD-3; TACTILE_SWITCH_SMD-3
TP201, TP202: TESTPOINT_ROUND; TESTPAD_ROUND
U201: RP2040; QFN-56_EP
U202: W25Q_USON; USON8L-2X3MM
X201: 403I35D12M00000; CRYSTAL-3.2-2.5

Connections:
BOOTSEL: R201.1, S201.4 (2)
FAN_NEW: R222.1, U201.36 (GPIO24)
FAN_SENSE: D204.4 (CH2), R220.1, U201.37 (GPIO25)
GND: C201.2, C202.2, C203.2, C204.2, C205.2, C206.2, C207.2, D201.2 (VN), D202.2 (VN), D204.2 (VN), J201.1, J202.1, J203.5, J203.SH1, J203.SH2, J203.SH3, J203.SH4, J203.SH5, J203.SH6, J204.1, J204.3, J204.5, J204.7, J205.1, J205.3, J205.5, J205.7, J207.2, LED201.C, LED202.C, LED203.C, Q201.2 (S), R210.1, R217.1, R218.1, S201.1, U201.19 (TESTEN), U202.4 (GND), X201.2 (GND), X201.4 (GND); also elsewhere on the board
unnamed: C206.1, U201.20 (XIN), X201.3 (C2)
unnamed: C205.1, R213.2, X201.1 (C1)
unnamed: R213.1, U201.21 (XOUT)
unnamed: R209.1, U201.47 (USB_DP)
unnamed: R211.1, U201.46 (USB_DN)
unnamed: J203.2, R211.2
unnamed: J203.3, R209.2
unnamed: LED203.A, R219.1
unnamed: J206.3, R220.2, R221.1
unnamed: LED202.A, R216.1
unnamed: LED201.A, R215.1
unnamed: D203.A, J206.1, Q201.3 (D)
unnamed: Q201.1 (G), R217.2, R222.2
QSPI_SCLK: U201.52 (QSPI_SCLK), U202.6 (CLK)
QSPI_SD0: U201.53 (QSPI_SD0), U202.5 (DI/IO[0])
QSPI_SD1: U201.55 (QSPI_SD1), U202.2 (DO/IO[1])
QSPI_SD2: U201.54 (QSPI_SD2), U202.3 (#WP/IO[2])
QSPI_SD3: U201.51 (QSPI_SD3), U202.7 (#HOLD/IO[3])
QSPI_SS_N: R201.2, R202.1, U201.56 (QSPI_SS_N), U202.1 (/CS)
RPFP_D0: J205.2, U201.15 (GPIO12); also elsewhere on the board
RPFP_D1: J205.4, U201.16 (GPIO13); also elsewhere on the board
RPFP_D2: J205.6, U201.17 (GPIO14); also elsewhere on the board
RPFP_D3: J205.8, U201.18 (GPIO15); also elsewhere on the board
RPFP_D4: U201.27 (GPIO16); also elsewhere on the board
RPFP_D5: U201.28 (GPIO17); also elsewhere on the board
RPFP_D6: U201.29 (GPIO18); also elsewhere on the board
RPFP_D7: U201.30 (GPIO19); also elsewhere on the board
RPFP_D8: J204.2, U201.31 (GPIO20); also elsewhere on the board
RPFP_D9: J204.4, U201.32 (GPIO21); also elsewhere on the board
RPFP_D10: J204.6, U201.34 (GPIO22); also elsewhere on the board
RPFP_D11: J204.8, U201.35 (GPIO23); also elsewhere on the board
RPFP_RUN: R205.1, TP201.P$1, U201.26 (RUN); also elsewhere on the board
RPI0_GPIO18: U201.4 (GPIO02); also elsewhere on the board
RPI0_GPIO24: R212.1; also elsewhere on the board
RPI0_GPIO25: R214.1; also elsewhere on the board
RPI0_RX0: U201.2 (GPIO00); also elsewhere on the board
RPI0_TX0: U201.3 (GPIO01); also elsewhere on the board
RPIP_AUXIO0: U201.41 (GPIO29/ADC3); also elsewhere on the board
RPIP_AUXIO1: U201.39 (GPIO27/ADC1); also elsewhere on the board
RPIP_BTN: R218.2, S202.1, U201.8 (GPIO06)
RPIP_BUZZ: U201.9 (GPIO07); also elsewhere on the board
RPIP_LED0: R215.2, U201.7 (GPIO05)
RPIP_LED1: R216.2, U201.6 (GPIO04)
RPIP_LED2: R219.2, U201.5 (GPIO03)
RPIP_SCL0: D201.3 (CH1), J201.4, R204.1, U201.12 (GPIO09)
RPIP_SCL1: D202.3 (CH1), J202.4, R208.1, U201.14 (GPIO11); also elsewhere on the board
RPIP_SDA0: D201.4 (CH2), J201.3, R203.1, U201.11 (GPIO08)
RPIP_SDA1: D202.4 (CH2), J202.3, R207.1, U201.13 (GPIO10); also elsewhere on the board
SWCLK: J207.3, R214.2, U201.24 (SWCLK)
SWDIO: J207.1, R212.2, U201.25 (SWDIO)
V3P3: C202.1, D201.6 (VP), D202.6 (VP), D204.6 (VP), F201.1, F202.1, R202.2, R203.2, R204.2, R205.2, R207.2, R208.2, R221.2, S202.4 (2), U202.8 (VCC); also elsewhere on the board
V3P3_J201: C201.1, F201.2, J201.2
V3P3_J202: C203.1, F202.2, J202.2
V12: F203.1, R206.2; also elsewhere on the board
V12_CURR_SENSE: U201.38 (GPIO26/ADC0); also elsewhere on the board
V12_FAN: C207.1, D203.C, F203.2, J206.2
VBUS: J203.1, TP202.P$1
VIN_SENSE: C204.1, D204.3 (CH1), R206.1, R210.2, U201.40 (GPIO28/ADC2)

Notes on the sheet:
BOOTSEL (force USB boot)
CTS-Frequency Controls 403I35D12M00000
RP2040 MCU (RPi Pico)
RPiP Qwiic0
RPiP Qwiic1
Debug
To RPi 0 J101 page 1
To FPGA U301 page 3
To Aux Coax J505 page 5
MISO
SCLK
MOSI
UART_ACC_TO_FPGA
UART_FPGA_TO_ACC
ACC_BOARD_SELECT
ACC_END_CYC
ACC_STATUS_SELECT
ACC_RUN_IND

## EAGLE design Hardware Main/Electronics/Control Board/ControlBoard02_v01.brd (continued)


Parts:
C301: 0.1u; 0402-CAP
J301: M04X2_0.050_SMD_NO_CREAM
J302: M03X2PTH; 2X3-NS
J303, J304: M05X2_SMD_0.050_NOCREAM; M05X2_0.050_SMD_NO_CREAM
LED301, LED303, LED305: LTST-C191KRKT; LED-0603
LED302, LED304, LED306: LTST-C191KGKT; LED-0603
R301, R302, R305, R306, R307, R312: 10k; 0402-RES
R303, R304: DNP; 0402-RES
R308, R309, R310, R311, R313, R314: 470; 0402-RES
TP301: TESTPOINT_ROUND; TESTPAD_ROUND
TP302: TESTPOINTPADSMALL; TESTPAD_SMALL
U301: MACHXO2_FTBGA256; LBGA-256
XO301: OSCILLATOR_TXO2520; TXO2520

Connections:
ADS_CSN0: U301.H5 (PL9C); also elsewhere on the board
ADS_CSN1: U301.C1 (PL2C); also elsewhere on the board
ADS_CSN2: U301.K12 (PR11D); also elsewhere on the board
ADS_SCK0: U301.F5 (PL5C); also elsewhere on the board
ADS_SCK1: U301.B1 (PL1C); also elsewhere on the board
ADS_SCK2: U301.J12 (PR6D); also elsewhere on the board
ADS_SDO0: U301.G5 (PL4C); also elsewhere on the board
ADS_SDO1: U301.C2 (PL1D); also elsewhere on the board
ADS_SDO2: U301.K14 (PR10A); also elsewhere on the board
AUXIO0: U301.B3 (PT9C); also elsewhere on the board
AUXIO1: U301.A3 (PT11C); also elsewhere on the board
AUXIO2: U301.H13 (PR6C); also elsewhere on the board
DETB_END_CYC0: U301.R7 (PB9A); also elsewhere on the board
DETB_END_CYC1: U301.P1 (PL13D); also elsewhere on the board
DETB_END_CYC2: U301.J1 (PL7C/PCLKT4_0); also elsewhere on the board
DETB_END_CYC3: U301.D1 (PL1B/L_GPLLC_FB); also elsewhere on the board
DETB_RUN0: U301.T5 (PB6A); also elsewhere on the board
DETB_RUN1: U301.N3 (PL14B); also elsewhere on the board
DETB_RUN2: U301.K5 (PL12C); also elsewhere on the board
DETB_RUN3: U301.E3 (PL2B/L_GPLLC_IN); also elsewhere on the board
DETB_SELECT00: U301.R9 (PB18A); also elsewhere on the board
DETB_SELECT01: U301.R11 (PB22A); also elsewhere on the board
DETB_SELECT02: U301.T9 (PB16A/PCLKT2_1); also elsewhere on the board
DETB_SELECT03: U301.N9 (PB16D); also elsewhere on the board
DETB_SELECT04: U301.N11 (PB21D); also elsewhere on the board
DETB_SELECT05: U301.P9 (PB16B/PCLKC2_1); also elsewhere on the board
DETB_SELECT06: U301.T2 (PB3C); also elsewhere on the board
DETB_SELECT07: U301.T4 (PB3B); also elsewhere on the board
DETB_SELECT08: U301.R4 (PB6D); also elsewhere on the board
DETB_SELECT09: U301.P5 (PB5B); also elsewhere on the board
DETB_SELECT10: U301.N8 (PB12C); also elsewhere on the board
DETB_SELECT11: U301.N6 (PB8C); also elsewhere on the board
DETB_SELECT12: U301.K2 (PL10B); also elsewhere on the board
DETB_SELECT13: U301.M2 (PL14A); also elsewhere on the board
DETB_SELECT14: U301.M1 (PL12B/PCLKC3_0); also elsewhere on the board
DETB_SELECT15: U301.J4 (PL9D); also elsewhere on the board
DETB_SELECT16: U301.L4 (PL12D); also elsewhere on the board
DETB_SELECT17: U301.L3 (PL11B); also elsewhere on the board
DETB_SELECT18: U301.F2 (PL3B/PCLKC5_0); also elsewhere on the board
DETB_SELECT19: U301.H2 (PL6B); also elsewhere on the board
DETB_SELECT20: U301.G1 (PL6A); also elsewhere on the board
DETB_SELECT21: U301.F4 (PL3C); also elsewhere on the board
DETB_SELECT22: U301.H4 (PL6C); also elsewhere on the board
DETB_SELECT23: U301.G3 (PL5B); also elsewhere on the board
DETB_STATUS_SELECT0: U301.R6 (PB6B); also elsewhere on the board
DETB_STATUS_SELECT1: U301.N2 (PL13C); also elsewhere on the board
DETB_STATUS_SELECT2: U301.J2 (PL9A); also elsewhere on the board
DETB_STATUS_SELECT3: U301.D2 (PL2D); also elsewhere on the board
DETB_TRIGGER0: U301.T7 (PB11A/PCLKT2_0); also elsewhere on the board
DETB_TRIGGER1: U301.P2 (PL14D); also elsewhere on the board
DETB_TRIGGER2: U301.J3 (PL7D/PCLKC4_0); also elsewhere on the board
DETB_TRIGGER3: U301.E2 (PL2A/L_GPLLT_IN); also elsewhere on the board
EXP_J303_D0: J303.2, U301.C5 (PT10B/HS)
EXP_J303_D1: J303.4, U301.D6 (PT12A/HS)
EXP_J303_D2: J303.6, U301.D7 (PT13D)
EXP_J303_D3: J303.8, U301.C7 (PT13B/HS)
EXP_J304_D0: J304.2, U301.H16 (PR7B/PCLKC1_0)
EXP_J304_D1: J304.4, U301.H15 (PR6B)
EXP_J304_D2: J304.6, U301.G16 (PR6A)
EXP_J304_D3: J304.8, U301.G15 (PR5A)
EXP_J601_D0: U301.C10 (PT20C/JTAGENB); also elsewhere on the board
EXP_J601_D1: U301.B10 (PT20D/PROGRAMN); also elsewhere on the board
EXP_J601_D2: U301.A13 (PT24C/INITN); also elsewhere on the board
EXP_J601_D3: U301.E10 (PT20B/HS); also elsewhere on the board
EXP_J601_D4: U301.D11 (PT21D); also elsewhere on the board
EXP_J601_D5: U301.C12 (PT23A/HS); also elsewhere on the board
EXP_J601_D6: U301.C13 (PT24D/DONE); also elsewhere on the board
FP_LED0: R308.2, U301.A15 (PT24B/HS)
FP_LED1: R309.2, U301.B14 (PT24A/HS)
FP_LED2: R310.2, U301.A14 (PT22D)
FP_LED3: R311.2, U301.B13 (PT22C)
FP_LED4: R313.2, U301.K13 (PR11C)
FP_LED5: R314.2, U301.J13 (PR9D)
FP_SCL: R301.1, R303.1, U301.A9 (PT18C/SCL/PCLKT0_0)
FP_SDA: R302.1, R304.1, U301.C9 (PT18D/SDA/PCLKC0_0)
GND: C301.2, J301.1, J301.3, J301.5, J301.7, J302.6, J303.1, J303.3, J303.5, J303.7, J303.9, J304.1, J304.3, J304.5, J304.7, J304.9, LED301.C, LED302.C, LED303.C, LED304.C, LED305.C, LED306.C, R312.1, XO301.2 (GND); also elsewhere on the board
unnamed: LED301.A, R308.1
unnamed: LED302.A, R309.1
unnamed: LED303.A, R310.1
unnamed: LED304.A, R311.1
unnamed: LED305.A, R313.1
unnamed: LED306.A, R314.1
OSC_CLK: U301.C8 (PT17A/HS/PCLKT0_1), XO301.3 (OUT)
RAM0_CEN: U301.K16 (PR9B); also elsewhere on the board
RAM0_SCLK: U301.K15 (PR10B); also elsewhere on the board
RAM0_SIO0: U301.L16 (PR11A); also elsewhere on the board
RAM0_SIO1: U301.J15 (PR9A); also elsewhere on the board
RAM0_SIO2: U301.J16 (PR7C); also elsewhere on the board
RAM0_SIO3: U301.L15 (PR12A); also elsewhere on the board
RPFP_D0: U301.B16 (PR1D); also elsewhere on the board
RPFP_D1: U301.C15 (PR1C); also elsewhere on the board
RPFP_D2: U301.C16 (PR2C); also elsewhere on the board
RPFP_D3: U301.D15 (PR2D); also elsewhere on the board
RPFP_D4: U301.D16 (PR2A); also elsewhere on the board
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

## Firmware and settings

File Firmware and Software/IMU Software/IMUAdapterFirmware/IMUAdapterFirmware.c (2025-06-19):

// ---  NinjaNIRS 2025  ---
// Firmware for NN22_IMU_Adapter01_s00 board
//
// Initial version: 2024-04-10
// Bernhard Zimmermann - bzim@bu.edu
// Boston University Neurophotonics Center
//

// This firmware will display the output of an ISM330DHCX 6DOF IMU connected
// to a QWIIC port on the Control Board.
// To see the output, connect a terminal to the virtual COM port of the Pico USB.

#include <stdio.h>
#include "pico/stdlib.h"
#include "pico/unique_id.h"
#include "imu_adapter_pins_consts.h"
#include "hardware/adc.h"
#include "hardware/pio.h"
#include "hardware/pll.h"
#include "hardware/clocks.h"
#include "uart_rx.pio.h"
#include "hardware/i2c.h"


uint16_t temp_dig;
uint16_t vimu_dig;
uint16_t imu_buf[N_EXT_IMUS+1][N_WORDS_PER_IMU]; // +1 for internal IMU

uint uart_rx_program_offset0;
uint uart_rx_program_offset1;

// function declarations
void refresh_imu_buf();
void refresh_adc_buf();
void strobe_imu_rx_all();
int int_acc_set_self_test(int8_t st_val);
int read_int_acc_raw(uint8_t res_buf[14]);
int init_int_acc();

int main() {
	const uint8_t PKT_HEADER[] = {253, 251};
	const uint8_t STATUS_PKT_HEADER[] = {239, 237};
	const uint8_t FIRMWARE_VERSION[] = {0, 0};
	const uint8_t PKT_LENGTH = 28; //make pkt len same as detector card for simplicity

	int ret = 0;
	uint ii, jj, iw;

	bool end_cyc_last = 0;
	bool end_cyc_curr;
	uint8_t cyc_cnt = 0;

	bool int_acc_connected;

	pico_unique_board_id_t board_id;

	/* PLL settings calculator:
	$ python pll_divs.py 96
	Requested: 96.0 MHz
	Achieved: 96.0 MHz
	FBDIV: 128 (VCO = 1536 MHz)
	PD1: 4
	PD2: 4
	*/
	clock_stop(clk_peri);
	clock_configure(clk_sys,
					CLOCKS_CLK_SYS_CTRL_SRC_VALUE_CLK_REF,
					0,
					12 * MHZ,
					12 * MHZ);
	pll_deinit(pll_sys);
	pll_init(pll_sys, 1, 1536 * MHZ, 4, 4);
	clock_configure(clk_sys,
					CLOCKS_CLK_SYS_CTRL_SRC_VALUE_CLKSRC_CLK_SYS_AUX,
					CLOCKS_CLK_SYS_CTRL_AUXSRC_VALUE_CLKSRC_PLL_SYS,
					96 * MHZ,
					96 * MHZ);
	clock_configure(clk_peri,
					0,
					CLOCKS_CLK_PERI_CTRL_AUXSRC_VALUE_CLKSRC_PLL_SYS,
					96 * MHZ,
					96 * MHZ);

	//stdio_init_all();

	// GPIO setup
	gpio_init(END_CYC_PIN); //input
	gpio_init(STATUS_SELECT_PIN); //input
	gpio_init(RESERVED_PIN);
	gpio_set_dir(RESERVED_PIN, GPIO_OUT);
	gpio_init(VIMU_EN_PIN);
	gpio_set_dir(VIMU_EN_PIN, GPIO_OUT);
	gpio_put(VIMU_EN_PIN, 0);
	gpio_init(LED_R_PIN);
	gpio_set_dir(LED_R_PIN, GPIO_OUT);
	gpio_init(LED_G_PIN);
	gpio_set_dir(LED_G_PIN, GPIO_OUT);
	gpio_put(LED_G_PIN, 1);

	// UART to IMU boards
	for (ii = 0; ii < N_EXT_IMUS; ii++){
		gpio_init(IMU_RX_PINS[ii]);
		gpio_set_dir(IMU_RX_PINS[ii], GPIO_OUT);
		gpio_put(IMU_RX_PINS[ii], 0);
	}

	// UART to FPGA on Control Board setup
	uart_init(uart0, 6000000);
	uart_set_hw_flow(uart0, true, false); // enable CTS (tx flow control)
	gpio_set_function(UART_TX_PIN, GPIO_FUNC_UART);
	gpio_set_function(UART_RX_PIN, GPIO_FUNC_UART);
	gpio_set_function(BOARD_SELECT_PIN, GPIO_FUNC_UART);
	
	// Internal ADC setup
	adc_init();
    adc_set_temp_sensor_enabled(true);
	adc_gpio_init(VIMU_SENSE_PIN);
    adc_select_input(TEMP_SENSE_ACH); // select temperature sensor
	temp_dig = adc_read();

	// Unique board ID - read from flash
	pico_get_unique_board_id(&board_id);

	// I2C initialisation. Using it at 200Khz.
    i2c_init(ACC_I2C, 200*1000);
    gpio_set_function(INT_IMU_SDA_PIN GPIO_FUNC_I2C);
    gpio_set_function(INT_IMU_SCL_PIN, GPIO_FUNC_I2C);
    gpio_pull_up(INT_IMU_SDA_PIN);
    gpio_pull_up(INT_IMU_SCL_PIN);

	// sleep for a random (but constant for each board) time
	sleep_us(((uint64_t)board_id.id[6]<<5) + 512);

	// turn on power to IMUs
	sleep_ms(5); // give extra time to properly reset IMU MCUs
	gpio_put(VIMU_EN_PIN, 1);

	// UART can power IMU through IO, so only set to 1 here
	for (ii = 0; ii < N_EXT_IMUS; ii++){
		gpio_put(IMU_RX_PINS[ii], 1);
	}
	sleep_ms(2);

	// PIO setup
	uart_rx_program_offset0 = pio_add_program(pio0, &uart_rx_program);
	uart_rx_program_offset1 = pio_add_program(pio1, &uart_rx_program);
	for(ii = 0; ii<4; ii++) {
		uart_rx_program_init(pio0, ii, uart_rx_program_offset0, IMU_TX_PINS[ii], IMU_BAUD_RATE);
	}
	for(ii = 0; ii<(N_EXT_IMUS-4); ii++) {
		uart_rx_program_init(pio1, ii, uart_rx_program_offset1, IMU_TX_PINS[ii+4], IMU_BAUD_RATE);
	}

	// Initialize internal accelerometer
	int_acc_connected = false;
	for(ii = 0; ii<3; ii++) {
		ret = init_acc();
		if (res==PICO_ERROR_GENERIC){ // Accelerometer not connected or not replying.
			sleep_us(100);
		} else {
			int_acc_connected = true;
			break;
		}
	}

	gpio_put(LED_G_PIN, 0);
	//uart_puts(uart0, "init\n");
	
	while (1) { // Main Loop
		end_cyc_curr = gpio_get(END_CYC_PIN);
		if (end_cyc_curr == 1 && end_cyc_last == 0) {
			if (gpio_get(STATUS_SELECT_PIN)) {
				// write status packet into uart fifo
				uart_write_blocking(uart0, STATUS_PKT_HEADER, 2);
				uart_putc_raw(uart0, (char)cyc_cnt);
				uart_write_blocking(uart0, board_id.id, 8);
				uart_write_blocking(uart0, FIRMWARE_VERSION, 2);
				uart_write_blocking(uart0, (uint8_t *) &temp_dig, 2);
				uart_putc_raw(uart0, 0); // future additional status info
				uart_putc_raw(uart0, 0); 
				uart_putc_raw(uart0, 0); 
				uart_putc_raw(uart0, 0); 
				uart_putc_raw(uart0, 0); 
				temp_dig = adc_read();
			} else {
				// write results packet into uart fifo
				uart_write_blocking(uart0, PKT_HEADER, 2);
				uart_putc_raw(uart0, (char)cyc_cnt);
				if (imu_buf[cyc_cnt%8][0] == (0xFF|0x0E<<8)) { // check for correct header of 255 and 14
					uart_write_blocking(uart0, (uint8_t *) &imu_buf[cyc_cnt%8][1], 14);
					// ToDo: Check or retransmit checksum
					// make packet lenght same as detector card
					for (ii = 0; ii < (PKT_LENGTH - 2-1-14-1); ii++){
						uart_putc_raw(uart0, 0);
					}
				} else { // transmit zeroes if IMU not connected 
					for (ii = 0; ii < (PKT_LENGTH - 2-1-1); ii++){
						uart_putc_raw(uart0, 0);
					}
				}
				uart_putc_raw(uart0, 0); //possibly tx crc in future
			}

			if (cyc_cnt%8 == 7) {
				refresh_imu_buf();
			}

			cyc_cnt += 1;
		}
		end_cyc_last = end_cyc_curr;

		gpio_put(RESERVED_PIN, 1); // for measuring loop execution duration
		asm volatile("nop"); //asm volatile("nop \n nop");
		gpio_put(RESERVED_PIN, 0);
	}
}

void refresh_imu_buf(){
	// This function will first read the IMU PIO FIFOs, then send a pulse to all IMUs to get the next sample.

	// clear header
	// if no data is received, the header will not be correct, and zeros will instead be sent
	for(uint ii = 0; ii<N_EXT_IMUS; ii++){
		imu_buf[ii][0] = 0;
	}

	for(uint ii = 0; ii<4; ii++) {
		if (pio_sm_is_rx_fifo_full(pio0, ii)) { // sucessfull IMU read should fill the 8-word fifo
			for(uint iw = 0; iw<N_WORDS_PER_IMU-1; iw++) {
				imu_buf[ii][iw] = ((uint16_t *) &pio0->rxf[ii])[1];
			}
			// IMU unit sends odd number of bytes, also last one doesn't fit in FIFO, but is stored in ISR
			// after reading above, the FIFO should now have space, so manually push
			pio_sm_exec(pio0, ii , pio_encode_jmp(uart_rx_program_offset0 + uart_rx_offset_uart_push));
			sleep_us(1); // give PIO time to push into FIFO
			imu_buf[ii][N_WORDS_PER_IMU-1] = ((uint8_t *) &pio0->rxf[ii])[3];
		}
		if (pio_sm_is_rx_fifo_full(pio1, ii)) {
			for(uint iw = 0; iw<N_WORDS_PER_IMU-1; iw++) {
				imu_buf[ii+4][iw] = ((uint16_t *) &pio1->rxf[ii])[1];
			}
			pio_sm_exec(pio1, ii , pio_encode_jmp(uart_rx_program_offset1 + uart_rx_offset_uart_push));
			sleep_us(1);
			imu_buf[ii+4][N_WORDS_PER_IMU-1] = ((uint8_t *) &pio1->rxf[ii])[3];
		}
	}

	// flush fifos (just to make sure)
	for(uint ii = 0; ii<4; ii++) {
		pio_sm_clear_fifos(pio0, ii);
		pio_sm_clear_fifos(pio1, ii);
	}
	// request data from all IMUs
	strobe_imu_rx_all();
	// new data should arrive within 1.2 ms and will be ready when this function will be called next after 8 states
	return;
}

void refresh_adc_buf(){
	adc_select_input(TEMP_SENSE_ACH); // select temperature sensor
	temp_dig = adc_read();
	adc_select_input(VIMU_SENSE_ACH); // select voltage divider
	vimu_dig = adc_read();
	if (vimu_dig<2500) { // IMU voltage <~4V, fuse tripped?
		for (uint ii = 0; ii<4; ii++){
			pio_sm_set_enabled(pio0, ii, false);
			pio_sm_set_enabled(pio1, ii, false);
		}
		gpio_put(VIMU_EN_PIN, 0);
		// UART can power IMU through IO, so only set to 0 here
		for (uint ii = 0; ii < N_EXT_IMUS; ii++){
			gpio_put(IMU_RX_PINS[ii], 0);
			gpio_pull_down(IMU_TX_PINS[ii]);
		}
	}
	return;
}

void strobe_imu_rx_all(){
	for (uint ii = 0; ii < N_EXT_IMUS; ii++){
		gpio_put(IMU_RX_PINS[ii], 0);
	}
	sleep_us(1000000/IMU_BAUD_RATE);
	for (uint ii = 0; ii < N_EXT_IMUS; ii++){
		gpio_put(IMU_RX_PINS[ii], 1);
	}
}

int int_acc_set_self_test(int8_t st_val)
{
    // this function enables the accelerometer and gyro self test
    // st_val = -1: negative self test (both gyro and acc)
    // st_val = 0: self_test off
    // st_val = 1: positive self test (both gyro and acc)

    uint8_t buf[2];

    buf[0] = ACC_CTRL5_C_ADDR;
    if (st_val==-1) { // negative self-test
        buf[1] = 0b00001110;
    } else if (st_val==1) { // positive self-test
        buf[1] = 0b00000101;
    } else { // normal mode (self-test off)
        buf[1] = 0;
    }
    i2c_write_blocking(ACC_I2C, ACC_ADDR, buf, 2, false);
    return 0;
}

int read_int_acc_raw(uint8_t res_buf[14])
{
    // this function reads temperature, accelerometer, and gyro data into res_buf
    i2c_write_blocking(ACC_I2C, ACC_ADDR, &ACC_OUT_TEMP_L_ADDR, 1, true);
    return i2c_read_blocking(ACC_I2C, ACC_ADDR, res_buf, 14, false);
}

int init_int_acc()
{
    // this fuction resets and initializes the ISM330DHCX IMU

    int res = 0;
    uint8_t buf[3];

    // check whether "who am i" register is ok
    res = i2c_write_blocking(ACC_I2C, ACC_ADDR, &ACC_WHO_AM_I_ADDR, 1, true);
    if (res==PICO_ERROR_GENERIC) { // acc not replying to I2C address/command
        return PICO_ERROR_GENERIC;
    } else {
        i2c_read_blocking(ACC_I2C, ACC_ADDR, buf, 1, false);
        if (buf[0]!=ACC_WHO_AM_I_VAL){ // not the correct model connected
            return PICO_ERROR_GENERIC;
        }
    }  

    // reset the acc
    buf[0] = ACC_CTRL3_C_ADDR;
    buf[1] = ACC_CTRL3_C_VAL;
    i2c_write_blocking(ACC_I2C, ACC_ADDR, buf, 2, false);
    sleep_us(100);

    // config acc
    buf[0] = ACC_CTRL1_XL_ADDR;
    buf[1] = ACC_CTRL1_XL_VAL;
    buf[2] = ACC_CTRL2_G_VAL;
    i2c_write_blocking(ACC_I2C, ACC_ADDR, buf, 3, false);

    //read back and verify
    buf[0]=0;
    buf[1]=0;
    i2c_write_blocking(ACC_I2C, ACC_ADDR, &ACC_CTRL1_XL_ADDR, 1, true);
    i2c_read_blocking(ACC_I2C, ACC_ADDR, buf, 2, false);
    if (buf[0]!=ACC_CTRL1_XL_VAL || buf[1]!=ACC_CTRL2_G_VAL){
        return PICO_ERROR_GENERIC;
    }

    return 0;
}

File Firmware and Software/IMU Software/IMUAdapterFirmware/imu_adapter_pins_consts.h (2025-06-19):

// ---  NinjaNIRS 2025  ---
// Pin constants for NN22_IMU_Adapter01_s00 board
//
// Initial version: 2024-04-10
// Bernhard Zimmermann - bzim@bu.edu
// Boston University Neurophotonics Center
//


// Backplane pins: GPIO00 - GPIO06
const uint UART_TX_PIN = 0;
const uint UART_RX_PIN = 1;
const uint BOARD_SELECT_PIN = 2;
//const uint TRG_PIN = 3; // check also adcacq.pio
const uint END_CYC_PIN = 4;
const uint STATUS_SELECT_PIN = 5;
const uint RESERVED_PIN = 6;

// Misc Pins
const uint VIMU_EN_PIN = 10;
const uint LED_R_PIN = 8;
const uint LED_G_PIN = 7;
const uint VIMU_SENSE_PIN = 29;
const uint VIMU_SENSE_ACH = 3;

const uint TEMP_SENSE_ACH = 4;

// IMU pins
// RX: from IMU Adapter to IMU Board
// TX: from IMU Board to IMU Adapter
// (IMU Board centric labeling)
#define N_EXT_IMUS 7
const uint IMU_TX_PINS[] = {25, 17, 15, 19, 23, 27, 20};//{19, 21, 23, 27, 25, 15, 17, 13};
const uint IMU_RX_PINS[] = {24, 16, 14, 18, 22, 26, 21};//{18, 20, 22, 26, 24, 14, 16, 12};

const uint INT_IMU_SDA_PIN = 12;
const uint INT_IMU_SCL_PIN = 13;
#define INT_ACC_I2C i2c1

// IMU constants

// scaling factors and offsets
// const float ACC_ACCEL_SCF = 4.0/(2<<14);
// const float ACC_GYRO_SCF = 250.0/(2<<14);
// const float ACC_TEMP_SCF = 1.0/256;
// const float ACC_TEMP_OFFSET = 25.0;


const uint IMU_BAUD_RATE = 250000;
const uint N_BYTES_PER_IMU = 17;
#define N_WORDS_PER_IMU 9

// Address of ISM330DHCX 6DOF IMU
// 0x6A if SA0 = low, 0x6B if SA0 = high
// (SA0 pin on sparkfun board is pulled high by default)
const uint8_t ACC_ADDR= 0x6A;
const uint8_t ACC_WHO_AM_I_ADDR = 0x0F;
const uint8_t ACC_WHO_AM_I_VAL = 0x6B;
const uint8_t ACC_CTRL3_C_ADDR = 0x12; 
const uint8_t ACC_CTRL3_C_VAL = 0x03; // software reset
const uint8_t ACC_CTRL1_XL_ADDR = 0x10;
const uint8_t ACC_CTRL1_XL_VAL = 0b01111000; //accel ODR (833Hz) and FS (+-4g)
const uint8_t ACC_CTRL2_G_VAL = 0b01110000; //gyro ODR (833Hz) and FS (+-250dps)
const uint8_t ACC_OUT_TEMP_L_ADDR = 0x20; //start of output registers
const uint8_t ACC_CTRL5_C_ADDR = 0x14;

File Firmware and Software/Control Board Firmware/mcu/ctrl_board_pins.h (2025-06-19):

// ---  NinjaNIRS 2022  ---
// Pin constants for ControlBoard02_v01 board
// This is the new control board with LCMXO2-7000HC FPGA.
//
// Initial version: 2024-04-19
// Bernhard Zimmermann - bzim@bu.edu
// Boston University Neurophotonics Center
//

// FPGA interface pins
const uint UART_TX_PIN = 12;
const uint UART_RX_PIN = 13;
const uint BOARD_SELECT_PIN = 14;  //CTS flow control
const uint END_CYC_PIN = 15;
const uint STATUS_SELECT_PIN = 16;
const uint RUN_IND_PIN = 17; // Run indicator input

// Qwiic RPiP1 port
const uint I2C1_SDA_PIN = 10;
const uint I2C1_SCL_PIN = 11;
#define ACC_I2C i2c1

// Misc Pins
const uint LED_R_PIN = 5;
const uint LED_G_PINS[] = {4, 3};
const uint BUTTON_PIN = 6;
const uint BUZZER_PIN = 7;
const uint FAN_PWR_PIN = 24;
const uint FAN_SENSE_PIN = 25;
const uint V12_CURR_SENSE_PIN = 26;
const uint V12_CURR_SENSE_ACH = 0;
const uint AUXIO_PINS[] = {29, 27};
const uint AUXIO_ACHS[] = {3, 1};
const uint VIN_SENSE_PIN = 28;
const uint VIN_SENSE_ACH = 2;
const uint TEMP_ACH = 4; // Internal temperature sensor virtual pin

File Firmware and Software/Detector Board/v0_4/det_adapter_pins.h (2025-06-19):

// ---  NinjaNIRS 2022  ---
// Pin constants for NN22_RPi_DetAdapter00_s02_R66R67 board
//
// Initial version: 2022-12-12
// Major revision: 2024-04-14 (2 wire ADC read)
// Bernhard Zimmermann - bzim@bu.edu
// Boston University Neurophotonics Center
//


// Backplane pins: GPIO00 - GPIO06
const uint UART_TX_PIN = 0;
const uint UART_RX_PIN = 1;
const uint BOARD_SELECT_PIN = 2;
//const uint TRG_PIN = 3; // check also adcacq_msin.pio
const uint END_CYC_PIN = 4;
const uint STATUS_SELECT_PIN = 5;
const uint RESERVED_PIN = 6;

// Misc Pins
const uint LED_PIN = 7;
const uint OPT_EN_VP_PIN = 8;
const uint OPT_EN_VN_PIN = 9;

// ADC pins
// 4 ADCs with dual-data SPI interface
const uint CSN_A3_PIN = 12;
const uint SCLK_A3_PIN = 13;
const uint MOSI_A3_PIN = 14;
const uint MISO_A3_PIN = 15;
const uint MISOB_A3_PIN = 11;
 
const uint CSN_A1_PIN = 16;
const uint SCLK_A1_PIN = 17;
const uint MOSI_A1_PIN = 18;
const uint MISO_A1_PIN = 20;
const uint MISOB_A1_PIN = 19;

const uint CSN_A4_PIN = 21;
const uint SCLK_A4_PIN = 22;
const uint MOSI_A4_PIN = 23;
const uint MISO_A4_PIN = 24;
const uint MISOB_A4_PIN = 10;

const uint CSN_A2_PIN = 25;
const uint SCLK_A2_PIN = 26;
const uint MOSI_A2_PIN = 27;
const uint MISO_A2_PIN = 29;
const uint MISOB_A2_PIN = 28;

// Map adc results to detectors
const uint DET_ADC_MAP[] = {1, 0, 4, 5, 3, 2, 6, 7};

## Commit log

2025-06-23 Uploaded ninjaCasing and Setup Guide
    ninjaCasing uploaded with revised folder structure along with updated setup guide that links to the new repository
    [BackPlane_Support.step, CableClamp_Bottom.step, CableClamp_Mid.step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]
2025-10-18 Create CombinedBackplane01_BOM.txt
    Add backplane BOM
2025-10-18 Add source interface card BOM.
    [NN22_VCCS_SrcAdapter02_s00_BOM.xlsx]
2026-07-09 Add .PDF of backplane schematic
    [CombinedBackplane01.sch]
2026-07-09 Add source card gerber

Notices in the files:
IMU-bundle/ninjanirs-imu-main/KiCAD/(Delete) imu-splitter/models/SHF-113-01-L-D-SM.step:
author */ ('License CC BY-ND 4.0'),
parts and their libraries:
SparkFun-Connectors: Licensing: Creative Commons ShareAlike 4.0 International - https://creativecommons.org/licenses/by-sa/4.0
